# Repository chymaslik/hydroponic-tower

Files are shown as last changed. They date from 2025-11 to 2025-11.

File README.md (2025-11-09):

# Hydroponic Tower Controller

ESPHome custom component for automated hydroponic tower management with pump cycling and lighting control.

## Features

- **Pump Cycle Control**: Automatic ON/OFF cycling with configurable intervals
- **Light Scheduling**: Time-based lighting control with brightness adjustment
- **Web Interface**: Modern, responsive web UI for manual control and monitoring
- **Real-time State**: Live updates of pump and light status
- **REST API**: Full API for integration with Home Assistant or other systems

## Installation

Add this to your ESPHome YAML configuration:

```yaml
external_components:
  - source: github://chymaslik/hydroponic-tower@main
    components: [ hydroponic_controller ]

hydroponic_controller:
  pump_id: water_pump
  light_id: lighting
  time_id: sntp_time
  web_server_id: web_srv
  on_minutes: 5      # Pump ON duration
  off_minutes: 15    # Pump OFF duration
  enabled: false     # Start with schedule disabled
```

## Configuration Variables

- **pump_id** (*Required*, ID): ID of the fan component controlling the pump
- **light_id** (*Required*, ID): ID of the light component
- **time_id** (*Required*, ID): ID of the time component for scheduling
- **web_server_id** (*Required*, ID): ID of the web_server component
- **on_minutes** (*Optional*, int): Pump ON duration in minutes (1-120, default: 5)
- **off_minutes** (*Optional*, int): Pump OFF duration in minutes (1-120, default: 15)
- **enabled** (*Optional*, boolean): Enable pump schedule on startup (default: false)

## Hardware Requirements

- ESP32-C3 (or any ESP32 variant)
- MOSFET modules for pump and lighting control
- Water pump
- LED grow lights
- 12V power supply

## Web Interface

Access the web interface at `http://[device-ip]/` to:
- Manually control pump and lighting
- Configure pump cycle intervals
- Set light schedule (ON/OFF times)
- View real-time events log

## API Endpoints

- `GET /api/state` - Get current state
- `POST /api/pump?on=[0|1]&speed=[0-100]` - Control pump
- `POST /api/pump-cycle?enabled=[0|1]&on=[minutes]&off=[minutes]` - Configure pump schedule
- `POST /api/light?on=[0|1]&brightness=[0-100]` - Control lighting
- `POST /api/light-schedule?enabled=[0|1]&on=[minutes]&off=[minutes]` - Configure light schedule

## Example Configuration

See [hydroponics.yaml](hydroponics.yaml) for a complete working example.

## License

MIT License

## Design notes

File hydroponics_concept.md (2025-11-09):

# Концепция проекта "Умная гидропонная башня"

Этот документ описывает концепцию и компоненты для создания умной гидропонной установки башенного типа на базе 3D-модели "Modular Hydroponic Tower Garden" и микроконтроллера ESP32 с прошивкой ESPHome.

## 1. Концепция системы

Система предназначена для автоматизации ключевых процессов в гидропонной установке: контроль и поддержание уровня питательного раствора, управление освещением и мониторинг ключевых параметров воды (EC и pH).

**Принцип работы:**

- **Контроллер ESP32** является "мозгом" системы. Он собирает данные с сенсоров и управляет исполнительными устройствами.
- **Сенсоры** непрерывно или периодически измеряют параметры окружающей среды и питательного раствора.
- **Исполнительные устройства** (помпа и светодиодная лента) включаются по заданным алгоритмам (например, по расписанию или по показаниям датчиков).
- **Питание** всей системы осуществляется от одного блока питания на 12В, что упрощает конструкцию. Специализированная плата расширения или набор модулей обеспечивает распределение питания на все компоненты.
- **ESPHome** позволяет легко настроить всю логику работы через простой конфигурационный YAML-файл без необходимости глубокого программирования.

### Структурная схема

#### 1. Общая архитектура системы

```mermaid
graph TD;
    subgraph "Питание"
        PSU["Блок питания 12V"];
    end

    subgraph "Управление и Логика"
        CTL["Блок управления<br/>(ESP32 и модули)"];
    end

    subgraph "Исполнительные устройства"
        ACT["Помпа, LED лента"];
    end

    subgraph "Сенсоры и Камера"
        SNS["Все датчики"];
    end

    PSU -->|"12V"| CTL;
    PSU -->|"12V"| ACT;
    CTL -->|"Управляющий сигнал"| ACT;
    SNS -->|"Данные"| CTL;

    style PSU fill:#f9f,stroke:#333,stroke-width:2px;
    style ACT fill:#9cf,stroke:#333,stroke-width:2px;
    style SNS fill:#9cf,stroke:#333,stroke-width:2px;
```

#### 2. Схема подключения сенсоров к ESP32

```mermaid
graph TD;
    ESP32["ESP32 Dev Board"];

    subgraph "Сенсоры и Камера"
        Level["Ультразвуковой датчик уровня<br/>JSN-SR04T"];
        Light["Датчик света<br/>BH1750"];
        AirSensor["Темп. и влажность<br/>BME280"];
        WaterTemp["Температура воды<br/>DS18B20"];
        PH["Датчик pH<br/>DFRobot pH V2"];
        EC["Датчик EC<br/>DFRobot EC V2"];
        WaterFlow["Датчик потока<br/>YF-S201"];
        Camera["ESP32-CAM (Wi-Fi)"];
    end

    Level -- "GPIO23" --> ESP32;
    Light -- "I2C (SDA:21, SCL:22)" --> ESP32;
    AirSensor -- "I2C (SDA:21, SCL:22)" --> ESP32;
    WaterTemp -- "OneWire (GPIO4)" --> ESP32;
    PH -- "ADC (GPIO35)" --> ESP32;
    EC -- "ADC (GPIO34)" --> ESP32;
    WaterFlow -- "GPIO25" --> ESP32;
    Camera -.->|"Wi-Fi/API"| ESP32;
```

## 2. Список компонентов для покупки

Ниже приведен список рекомендованных и совместимых компонентов.

| Компонент | Назначение | Пример / Модель |
| :--- | :--- | :--- |
| **Управление** |
| Микроконтроллер | Мозг системы | ESP32 DEVKIT V1 (или любая плата на ESP-WROOM-32) |
| Плата расширения | Для удобного подключения проводов без пайки | ESP32 Terminal Adapter / Screw Shield |
| **Питание** |
| Блок питания | Питание всей установки | AC/DC 12V, 5A (или больше, в зависимости от длины и мощности ленты) |
| DC-DC Преобразователь | Понижение напряжения с 12В до 5В для ESP32 | DC-DC Step-Down Buck Converter (вход 12V, выход 5V 3A+) |
| **Сенсоры** |
| Ультразвуковой датчик уровня  | Измерение расстояния до воды | Ультразвуковой датчик JSN-SR04T |
| Датчик освещенности | Мониторинг естественного света | GY-30 / BH1750 (I2C интерфейс) |
| Датчик темп. и влажн. воздуха | Контроль микроклимата | BME280 (I2C интерфейс) |
| Датчик температуры воды | Контроль температуры питательного раствора | DS18B20 (в герметичном корпусе) |
| Датчик потока воды | Контроль работы помпы | YF-S201 |
| EC-метр | Измерение электропроводности раствора (концентрация солей) | DFRobot Gravity: Analog EC Sensor/Meter V2 (K=1.0) |
| pH-метр | Измерение кислотности раствора | DFRobot Gravity: Analog pH Sensor/Meter Pro Kit V2 |
| **Исполнительные устройства** |
| Освещение | Круговая фитолампа | Светодиодная лента 12V, фитоспектр. **Длину нужно подбирать под 3D модель!** |
| Драйвер для LED ленты | Управление 12В лентой с помощью ESP32 | MOSFET-модуль (например, IRF520 / AOD4184) |
| Водяная помпа | Подача раствора наверх башни | Погружная помпа DC 12V, производительность ~240-300 л/ч |
| Релейный модуль | Управление 12В помпой с помощью 5В сигнала от ESP32 | 1-канальный релейный модуль 5V |
| **Видеонаблюдение** |
| Камера | Удаленный мониторинг состояния растений | Модуль ESP32-CAM |
| **Прочее** |
| Корпус | Защита электроники от влаги | IP65/IP67 пластиковый корпус |
| Провода | Соединение компонентов | Jumper wires ( Dupont ), провода сечением 0.5мм² |
| Калибровочные растворы | Для точной настройки pH и EC сенсоров | Растворы pH (4.01, 7.00), EC (1413 us/cm, 12.88 ms/cm) |
| Клеммные колодки | Для распределения питания | Винтовые, на 4-8 контактов |

**Примечание по плате расширения:** Вместо поиска одной сложной платы, которая делает все, я рекомендую модульный подход. Установите ESP32 на плату с винтовыми клеммами (Terminal Adapter). Рядом в том же корпусе разместите мощный DC-DC преобразователь 12V->5V и релейный модуль. Это гибкое, надежное и легко обслуживаемое решение.

### 2.1. Распиновка (Pinout)

В таблице ниже приведена рекомендуемая распиновка для всех компонентов, подключаемых к главной плате ESP32.

| Компонент | Тип / Протокол | Пин на ESP32 |
| :--- | :--- | :--- |
| **Сенсоры** |
| Ультразвуковой датчик уровня | Ultrasonic | `Trig: GPIO23`, `Echo: GPIO19` |
| Датчик освещенности (BH1750) | I2C | `SDA: GPIO21`, `SCL: GPIO22` |
| Датчик темп./влажн. (BME280) | I2C | `SDA: GPIO21`, `SCL: GPIO22` |
| Датчик температуры воды (DS18B20) | One-Wire | `GPIO4` |
| Датчик потока воды (YF-S201) | GPIO (Pulse Counter) | `GPIO25` |
| EC-метр (DFRobot) | Analog (ADC) | `GPIO34` |
| pH-метр (DFRobot) | Analog (ADC) | `GPIO35` |
| **Исполнительные устройства** |
| LED лента (через MOSFET) | PWM | `GPIO13` |
| Водяная помпа (через реле) | GPIO (Digital) | `GPIO12` |
| **Камера** |
| ESP32-CAM | Wi-Fi | N/A (отдельное устройство) |

**Что такое АЦП (ADC)?** Это **А**налого-**ц**ифровой **п**реобразователь, встроенный в ESP32. Он нужен для "чтения" показаний с аналоговых датчиков (таких как pH и EC), которые выдают результат в виде изменяющегося напряжения. АЦП преобразует это напряжение в число, понятное микроконтроллеру. Покупать его отдельно не нужно.

### 2.2. Распределение питания

Для такого количества компонентов необходим организованный подход к питанию. Использование клеммных колодок — это лучшее решение, чтобы избежать беспорядка в проводах и обеспечить надежный контакт.

Вся система имеет три основные линии питания: **+12В**, **+5В** и общая **Земля (GND)**. Для правильной работы всех компонентов абсолютно необходимо, чтобы у них была общая "земля" (GND).

- **Линия +12В:** Водяная помпа, Светодиодная лента.
- **Линия +5В:** Плата ESP32, все сенсоры, релейный модуль.
- **Линия GND:** **Все** компоненты системы.

#### Схема организации питания

```mermaid
graph TD;
    subgraph "Источник"
        PSU["Блок питания 12V"];
    end

    subgraph "Преобразователь"
        DCDC["DC-DC 12V -> 5V"];
    end

    subgraph "Распределительные колодки"
        TB12["Клеммная колодка +12V"];
        TB5["Клеммная колодка +5V"];
        TB_GND["<b>Общая клеммная колодка GND</b>"];
    end

    subgraph "Потребители"
        PUMP_LED["Помпа и LED-лента"];
        ESP_SENSORS["ESP32, реле и все сенсоры"];
    end

    %% Connections
    PSU -- "+12V" --> TB12;
    PSU -- "GND" --> TB_GND;

    TB12 -- "+12V" --> DCDC;
    TB_GND -- "GND" --> DCDC;

    DCDC -- "+5V" --> TB5;

    TB12 -- "+12V" --> PUMP_LED;
    TB_GND -- "GND" --> PUMP_LED;

    TB5 -- "+5V" --> ESP_SENSORS;
    TB_GND -- "GND" --> ESP_SENSORS;

    style TB_GND fill:#ccc,stroke:#333,stroke-width:2px;
```

## 3. Программное обеспечение: ESPHome

ESPHome позволяет описать всю логику работы устройства в одном файле. Вся конфигурация для основного контроллера вынесена в файл `

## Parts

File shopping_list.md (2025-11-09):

# Список покупок для проекта "Умная гидропоника"

Ниже приведен список компонентов с поисковыми ссылками для сайта AliExpress.

| Компонент | Пример / Модель | Ссылка для поиска на AliExpress |
| :--- | :--- | :--- |
| **Управление** |
| Микроконтроллер | ESP32 DEVKIT V1 | [Найти](https://www.aliexpress.com/wholesale?SearchText=ESP32+DEVKIT+V1) |
| Плата расширения | ESP32 Terminal Adapter | [Найти](https://www.aliexpress.com/wholesale?SearchText=ESP32+Terminal+Adapter) |
| **Питание** |
| Блок питания | AC/DC 12V 5A | [Найти](https://www.aliexpress.com/wholesale?SearchText=power+supply+12v+5a) |
| DC-DC Преобразователь | DC-DC Step-Down LM2596S | [Найти](https://www.aliexpress.com/wholesale?SearchText=DC-DC+Step+Down+LM2596S) |
| **Сенсоры** |
| Датчик уровня воды | Ультразвуковой датчик JSN-SR04T | [Найти](https://www.aliexpress.com/wholesale?SearchText=JSN-SR04T) |
| Датчик освещенности | BH1750 | [Найти](https://www.aliexpress.com/wholesale?SearchText=BH1750+module) |
| Датчик темп./влажн. | BME280 | [Найти](https://www.aliexpress.com/wholesale?SearchText=BME280+module) |
| Датчик темп. воды | DS18B20 (водонепроницаемый) | [Найти](https://www.aliexpress.com/wholesale?SearchText=DS18B20+waterproof) |
| Датчик потока воды | YF-S201 | [Найти](https://www.aliexpress.com/wholesale?SearchText=YF-S201+water+flow) |
| EC-метр | TDS / EC Sensor Module | [Найти](https://www.aliexpress.com/wholesale?SearchText=TDS+EC+sensor+module) |
| pH-метр | pH Sensor Module (0-14 pH) | [Найти](https://www.aliexpress.com/wholesale?SearchText=pH+sensor+module+0-14) |
| **Исполнительные устройства** |
| Освещение | 12V Phyto LED Strip | [Найти](https://www.aliexpress.com/wholesale?SearchText=12v+phyto+led+strip+full+spectrum) |
| Драйвер для LED | IRF520 MOSFET Module | [Найти](https://www.aliexpress.com/wholesale?SearchText=IRF520+MOSFET+module) |
| Водяная помпа | Погружная помпа 12V 240L/h | [Найти](https://www.aliexpress.com/wholesale?SearchText=mini+submersible+pump+12v+240L) |
| Релейный модуль | 1-канальное реле 5V | [Найти](https://www.aliexpress.com/wholesale?SearchText=1+channel+relay+module+5v) |
| **Видеонаблюдение** |
| Камера | ESP32-CAM | [Найти](https://www.aliexpress.com/wholesale?SearchText=ESP32-CAM+MB) |
| **Прочее** |
| Провода | Dupont Jumper Wires | [Найти](https://www.aliexpress.com/wholesale?SearchText=dupont+jumper+wires) |
| Калибровочные растворы | pH & EC Calibration Solution | [Найти](https://www.aliexpress.com/wholesale?SearchText=ph+ec+calibration+solution) |
| Клеммные колодки | Screw Terminal Block | [Найти](https://www.aliexpress.com/wholesale?SearchText=screw+terminal+block) |

**Совет:** При покупке pH и EC сенсоров обратите внимание на комплектацию. Часто калибровочные растворы (в виде порошков) уже идут в комплекте с ними. Также, при покупке ESP32-CAM, выбирайте версию с программатором (MB), это сильно упростит первую прошивку.

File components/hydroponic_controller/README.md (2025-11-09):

# Hydroponic Controller Component

ESPHome custom component for hydroponic systems automation.

## Files

- `__init__.py` - Component configuration and setup
- `hydroponic_controller.h` - Main controller implementation with web interface

## Usage

See main [README.md](../../README.md) for installation and configuration instructions.

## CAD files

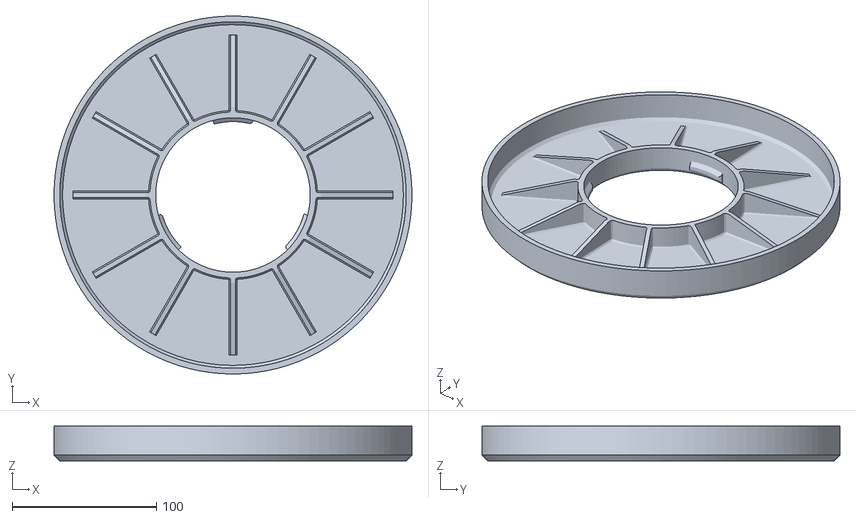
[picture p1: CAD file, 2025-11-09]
3d parts/ikea_muskot_pot_7_12_adapter_id240mm_full.stl
248.0 x 248.0 x 24.0

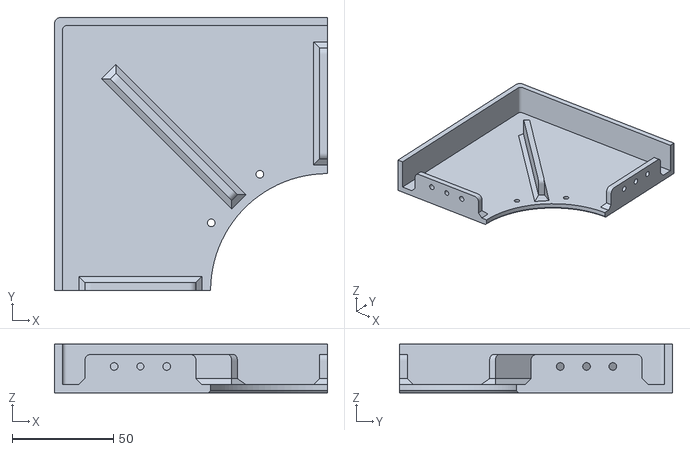
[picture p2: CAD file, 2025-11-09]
3d parts/lid v1.stl
135.0 x 135.0 x 24.0

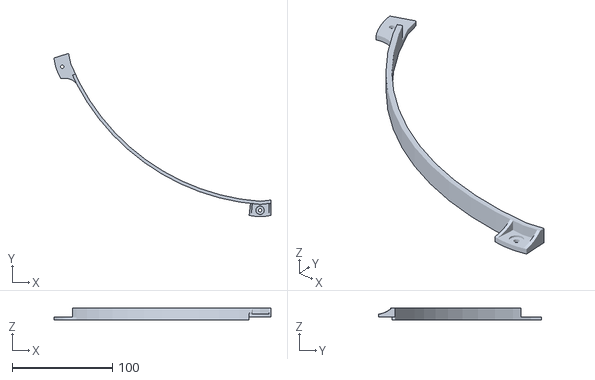
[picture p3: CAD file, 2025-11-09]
3d parts/rings_large_v42.stl
216.4 x 162.7 x 12.0

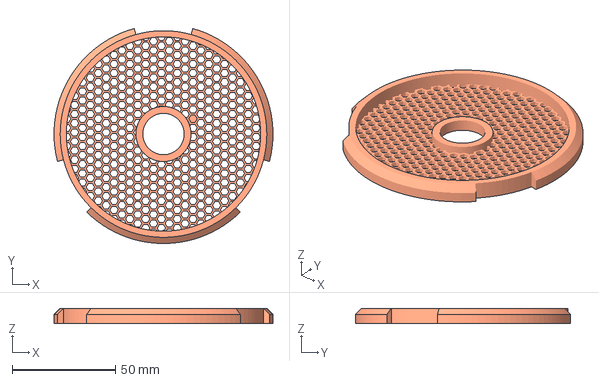
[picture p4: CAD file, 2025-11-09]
3d parts/filtration_mesh_remix.3mf
106.0 x 104.0 x 7.50 mm

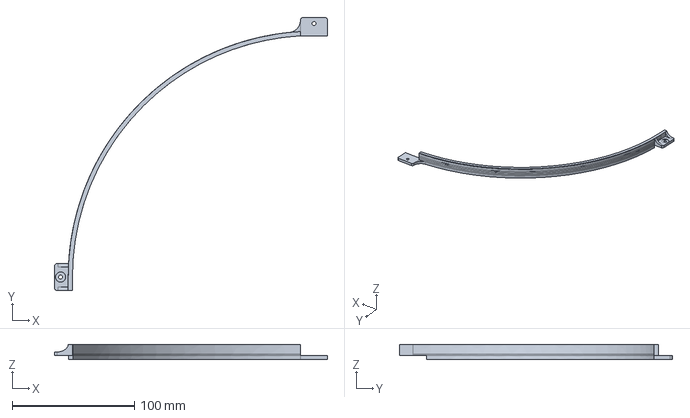
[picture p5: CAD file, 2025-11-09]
3d parts/ring_piece_for_4_way_cup.stp
223.2 x 223.2 x 12.0 mm

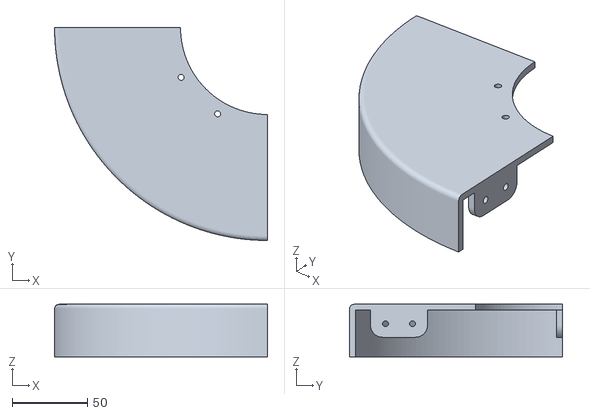
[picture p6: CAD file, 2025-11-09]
3d parts/Soporte_Basic.stl
142.0 x 142.0 x 35.0

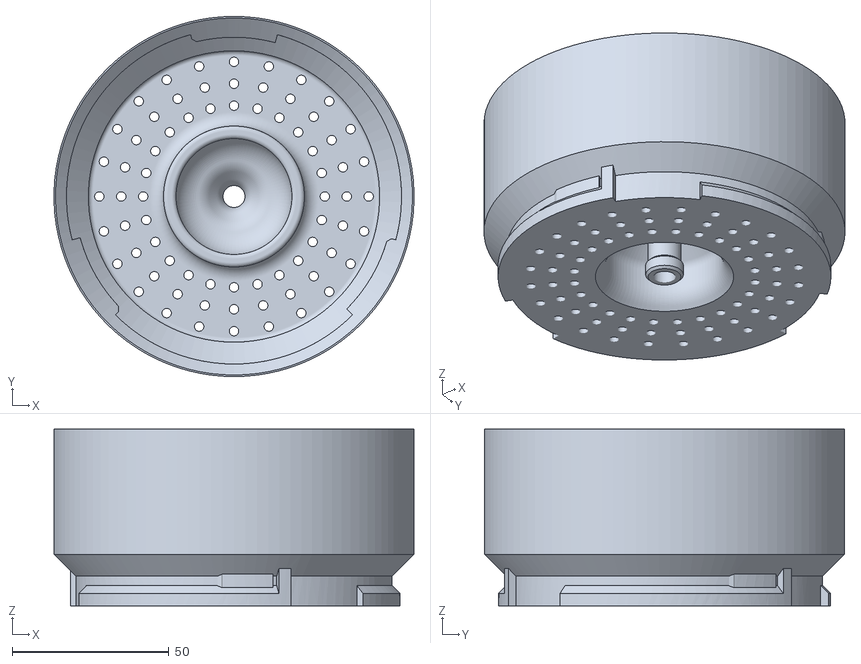
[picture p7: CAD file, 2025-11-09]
3d parts/dispenser_module_internal.stl
114.9 x 115.0 x 56.5

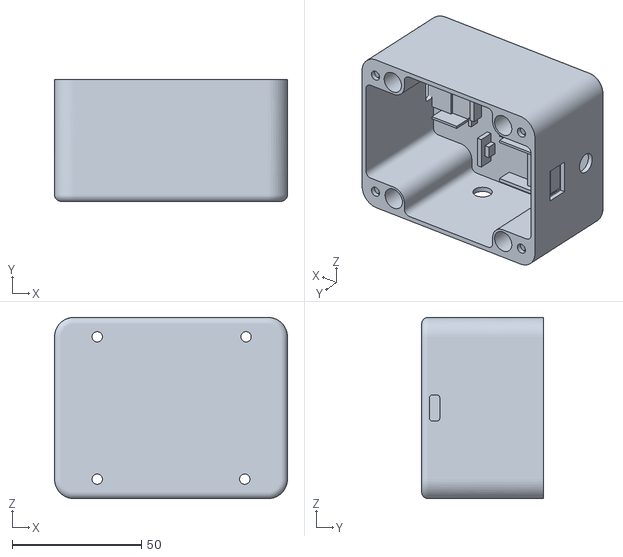
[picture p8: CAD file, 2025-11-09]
3d parts/electronic-box.stl
90.0 x 47.0 x 70.0

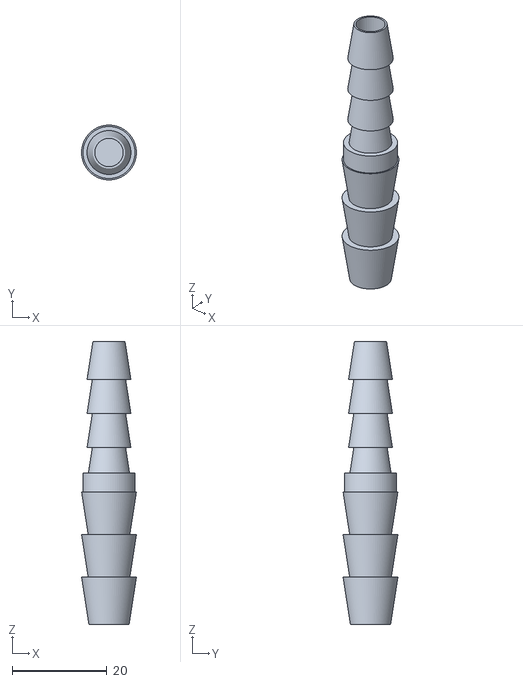
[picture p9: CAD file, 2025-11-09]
3d parts/10mmTo8mmHoseBarbAdapter.stl
11.6 x 11.6 x 59.8

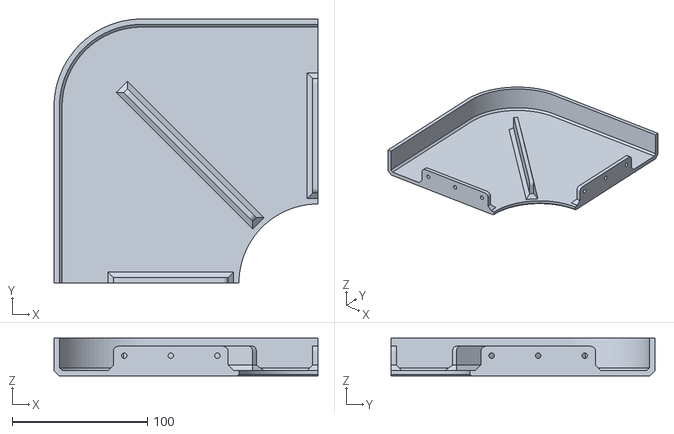
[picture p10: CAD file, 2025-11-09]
3d parts/oestlig_plant_pot_14_12x14_12_adapter.stl
195.5 x 195.5 x 28.0

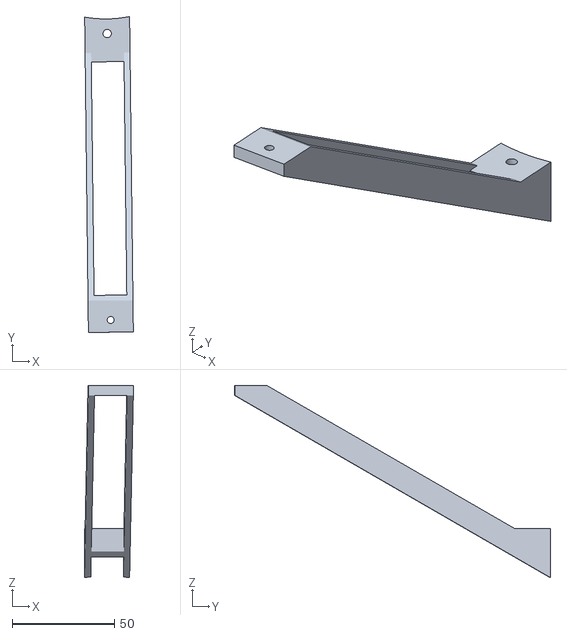
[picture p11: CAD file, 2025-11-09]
3d parts/arm_v2.stl
23.8 x 154.6 x 94.0

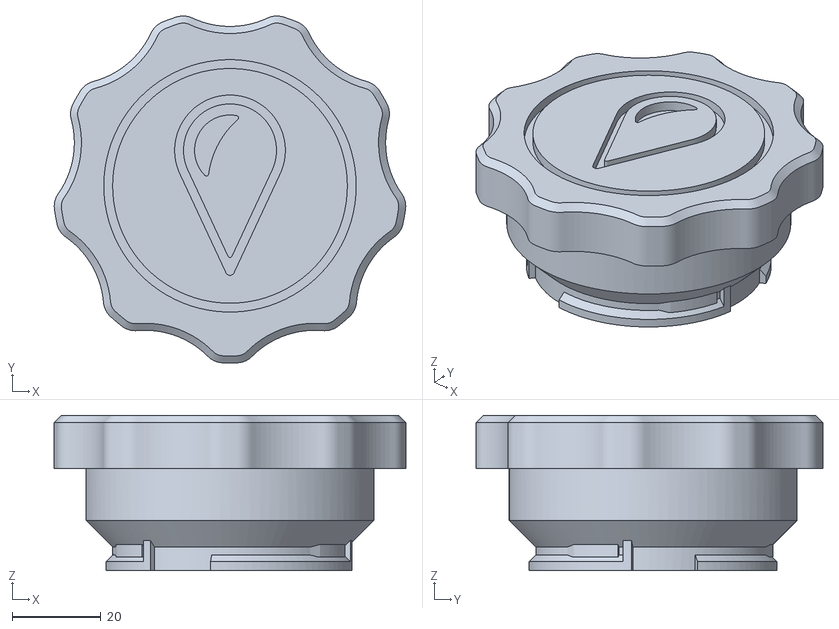
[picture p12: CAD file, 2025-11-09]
3d parts/filling_cap.stl
79.4 x 78.4 x 35.0

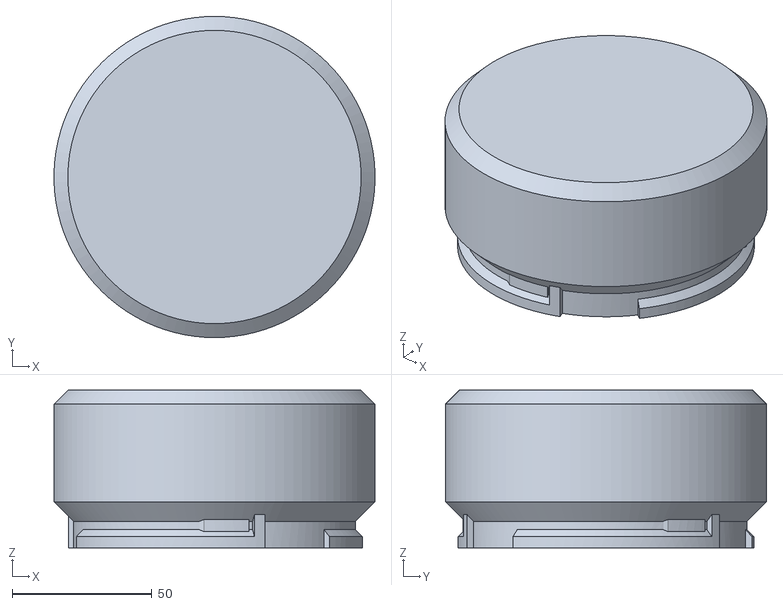
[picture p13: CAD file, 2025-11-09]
3d parts/lid_without_holes.stl
114.9 x 115.0 x 56.5

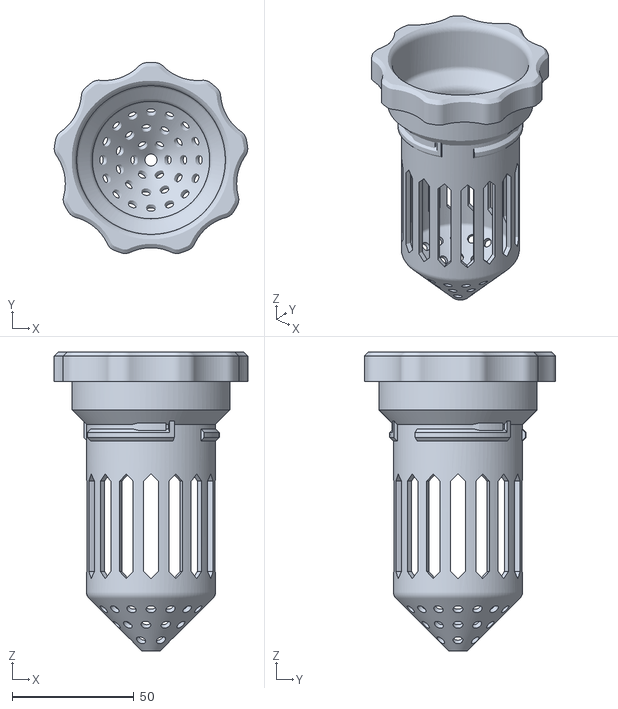
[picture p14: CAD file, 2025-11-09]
3d parts/standard_pot.stl
79.4 x 78.4 x 122.6

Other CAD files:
3d parts/3-way_planting_module_hollow.stl
3d parts/waterpump_hose_adapter.stl
3d parts/electronic-box-top.stl
3d parts/Base.stl
3d parts/1-way_planting_module_hollow_without_m3.stl
3d parts/4-way_planting_module_hollow.stl
3d parts/pump_holder.stl
3d parts/washer.stl

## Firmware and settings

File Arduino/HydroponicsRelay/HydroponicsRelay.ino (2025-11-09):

// Подключение Wi‑Fi и Web‑сервер
#include <WiFi.h>
#include <WebServer.h>
#include <time.h>
#include <sys/time.h>
#include <Preferences.h>

// Конфигурация пинов реле:
// IN1 -> GPIO41 (Lighting), IN2 -> GPIO42 (Pump)
const int relayLightingPin = 41;  // Канал 1 — освещение (IN1)
const int relayPumpPin     = 42;  // Канал 2 — помпа (IN2)

// Логика срабатывания реле: true для HIGH‑level (RY‑VCC↔VCC), false для LOW‑level (VOC↔GND)
const bool relayActiveHigh = false;  // инвертировано

// Скорость Serial для управления из монитора порта
const unsigned long serialBaudRate = 115200;

// Настройки Wi‑Fi (замените на свои)
const char* WIFI_SSID     = "Smart Home";
const char* WIFI_PASSWORD = "qazwsxedc";

// NTP/время
bool   ntpEnabled   = true;
long   gmtOffsetSec = 0;           // смещение от UTC в секундах
const char* NTP1 = "pool.ntp.org";
const char* NTP2 = "time.nist.gov";
unsigned long lastTimeSyncCheckMs = 0;

// NVS
Preferences prefs;

// HTTP сервер
WebServer server(80);
// Кольцевой буфер для последних N событий
struct Event { unsigned long ts; String msg; };
const size_t MAX_EVENTS = 50;
Event events[MAX_EVENTS];
size_t eventsHead = 0, eventsCount = 0;

// Параметры: помпа — циклический скедулер (в минутах)
struct CycleCfg { bool enabled; uint16_t onMin; uint16_t offMin; unsigned long lastTickMs; bool currentlyOn; };
CycleCfg schedPump { false, 1, 14, 0, false };

// Параметры: свет — расписание по времени суток (минуты с начала дня)
struct ClockCfg { bool enabled; uint16_t onMins; uint16_t offMins; bool lastAppliedOn; };
ClockCfg lightClock { false, 6*60, 22*60, false };

void saveConfig() {
  if (!prefs.begin("hydro", false)) return;
  prefs.putBool ("ntp", ntpEnabled);
  prefs.putLong ("tz",  gmtOffsetSec);
  prefs.putBool ("p_en", schedPump.enabled);
  prefs.putUShort("p_on", schedPump.onMin);
  prefs.putUShort("p_off",schedPump.offMin);
  prefs.putBool ("l_en", lightClock.enabled);
  prefs.putUShort("l_on", lightClock.onMins);
  prefs.putUShort("l_off",lightClock.offMins);
  prefs.end();
}

void loadConfig() {
  if (!prefs.begin("hydro", true)) return;
  ntpEnabled          = prefs.getBool ("ntp", ntpEnabled);
  gmtOffsetSec        = prefs.getLong ("tz",  gmtOffsetSec);
  schedPump.enabled   = prefs.getBool ("p_en", schedPump.enabled);
  schedPump.onMin     = prefs.getUShort("p_on", schedPump.onMin);
  schedPump.offMin    = prefs.getUShort("p_off",schedPump.offMin);
  lightClock.enabled  = prefs.getBool ("l_en", lightClock.enabled);
  lightClock.onMins   = prefs.getUShort("l_on", lightClock.onMins);
  lightClock.offMins  = prefs.getUShort("l_off", lightClock.offMins);
  prefs.end();
}

void pushEvent(const String &m) {
  events[eventsHead] = { millis(), m };
  eventsHead = (eventsHead + 1) % MAX_EVENTS;
  if (eventsCount < MAX_EVENTS) eventsCount++;
}

void setRelayState(int pinNumber, bool shouldTurnOn) {
  const int activeState   = relayActiveHigh ? HIGH : LOW;
  const int inactiveState = relayActiveHigh ? LOW  : HIGH;
  digitalWrite(pinNumber, shouldTurnOn ? activeState : inactiveState);
  String name = (pinNumber == relayLightingPin) ? F("Lighting") : F("Water pump");
  pushEvent(name + (shouldTurnOn ? F(" -> ON") : F(" -> OFF")));
}

void applyPumpCycle(CycleCfg &cfg, int pin) {
  if (!cfg.enabled) return;
  unsigned long now = millis();
  if (cfg.lastTickMs == 0) cfg.lastTickMs = now;
  unsigned long periodMs = (unsigned long)(cfg.currentlyOn ? cfg.onMin : cfg.offMin) * 60UL * 1000UL;
  if (periodMs == 0) return;
  if (now - cfg.lastTickMs >= periodMs) {
    cfg.currentlyOn = !cfg.currentlyOn;
    cfg.lastTickMs = now;
    setRelayState(pin, cfg.currentlyOn);
  }
}

// Вспомогательные функции для времени
bool getLocalTM(struct tm &out) {
  time_t now; time(&now);
  if (now < 100000) return false; // время не синхронизировано
  struct tm *lt = localtime(&now);
  if (!lt) return false;
  out = *lt; return true;
}

uint16_t hhmmToMins(const String &s) {
  int p = s.indexOf(':');
  if (p <= 0) return 0;
  int hh = s.substring(0,p).toInt();
  int mm = s.substring(p+1).toInt();
  if (hh < 0) hh=0; if (hh>23) hh=23; if (mm<0) mm=0; if (mm>59) mm=59;
  return (uint16_t)(hh*60+mm);
}

String minsToHHMM(uint16_t m) {
  uint16_t hh = (m/60)%24; uint16_t mm = m%60;
  char buf[6]; snprintf(buf,sizeof(buf), "%02u:%02u", (unsigned)hh,(unsigned)mm);
  return String(buf);
}

void applyLightByClock() {
  if (!lightClock.enabled) return;
  struct tm lt; if (!getLocalTM(lt)) return;
  uint16_t nowM = (uint16_t)(lt.tm_hour*60 + lt.tm_min);
  bool shouldOn;
  if (lightClock.onMins == lightClock.offMins) {
    shouldOn = false;
  } else if (lightClock.onMins < lightClock.offMins) {
    shouldOn = (nowM >= lightClock.onMins && nowM < lightClock.offMins);
  } else {
    // период через полночь
    shouldOn = (nowM >= lightClock.onMins || nowM < lightClock.offMins);
  }
  if (shouldOn != lightClock.lastAppliedOn) {
    lightClock.lastAppliedOn = shouldOn;
    setRelayState(relayLightingPin, shouldOn);
  }
}

void ensureTimeSync() {
  if (!ntpEnabled) return;
  if (WiFi.status() != WL_CONNECTED) return;
  unsigned long now = millis();
  if (lastTimeSyncCheckMs!=0 && now - lastTimeSyncCheckMs < 60000UL) return;
  lastTimeSyncCheckMs = now;
  static bool configured = false;
  if (!configured) {
    configTime(gmtOffsetSec, 0, NTP1, NTP2);
    configured = true;
  }
}

void printStatus() {
  int lightLevel = digitalRead(relayLightingPin);
  int pumpLevel  = digitalRead(relayPumpPin);
  const int activeState   = relayActiveHigh ? HIGH : LOW;
  Serial.println();
  Serial.println(F("== Relay status =="));
  Serial.print(F("Lighting: ")); Serial.println(lightLevel == activeState ? F("ON") : F("OFF"));
  Serial.print(F("Pump    : ")); Serial.println(pumpLevel  == activeState ? F("ON") : F("OFF"));
  Serial.println();
}

String jsonStatus() {
  const int activeState = relayActiveHigh ? HIGH : LOW;
  bool lightOn = (digitalRead(relayLightingPin) == activeState);
  bool pumpOn  = (digitalRead(relayPumpPin)     == activeState);
  struct tm lt; bool tv = getLocalTM(lt);
  char tbuf[20]=""; if (tv) snprintf(tbuf,sizeof(tbuf), "%04d-%02d-%02d %02d:%02d:%02d",
    lt.tm_year+1900, lt.tm_mon+1, lt.tm_mday, lt.tm_hour, lt.tm_min, lt.tm_sec);
  String json = "{";
  json += "\"lighting\":"; json += lightOn?"true":"false";
  json += ",\"pump\":";     json += pumpOn?"true":"false";
  json += ",\"time\":\"";   json += String(tbuf); json += "\"";
  json += ",\"ntp\":";      json += ntpEnabled?"true":"false";
  json += ",\"tz\":";       json += gmtOffsetSec;
  json += ",\"sched\":{\"lightClock\":{\"en\":"; json += lightClock.enabled?"true":"false";
  json += ",\"on\":\""; json += minsToHHMM(lightClock.onMins); json += "\"";
  json += ",\"off\":\""; json += minsToHHMM(lightClock.offMins); json += "\"";
  json += "},\"pump\":{\"en\":"; json += schedPump.enabled?"true":"false"; json += ",\"on\":"; json += schedPump.onMin; json += ",\"off\":"; json += schedPump.offMin; json += "}}}";
  return json;
}

void handleStatus() {
  server.sendHeader("Cache-Control", "no-cache, no-store, must-revalidate");
  server.sendHeader("Pragma", "no-cache");
  server.sendHeader("Expires", "0");
  server.send(200, "application/json", jsonStatus());
}

void handleRelayApi() {
  // /api/relay?ch=1&on=1
  if (!server.hasArg("ch") || !server.hasArg("on")) {
    server.send(400, "application/json", "{\"error\":\"params ch,on required\"}");
    return;
  }
  int ch = server.arg("ch").toInt();
  bool on = (server.arg("on") == "1" || server.arg("on") == "true");
  if (ch == 1)      { setRelayState(relayLightingPin, on); lightClock.lastAppliedOn = on; }
  else if (ch == 2) { setRelayState(relayPumpPin, on);     schedPump.currentlyOn  = on; schedPump.lastTickMs  = millis(); }
  else { server.send(400, "application/json", "{\"error\":\"ch must be 1 or 2\"}"); return; }
  server.sendHeader("Cache-Control", "no-cache, no-store, must-revalidate");
  server.sendHeader("Pragma", "no-cache");
  server.sendHeader("Expires", "0");
  server.send(200, "application/json", jsonStatus());
}

void handleEvents() {
  String json = "[";
  for (size_t i = 0; i < eventsCount; i++) {
    size_t idx = (eventsHead + MAX_EVENTS - eventsCount + i) % MAX_EVENTS;
    if (i) json += ',';
    json += '{';
    json += "\"ts\":"; json += events[idx].ts; json += ',';
    json += "\"msg\":\""; json += events[idx].msg; json += "\"";
    json += '}';
  }
  json += "]";
  server.sendHeader("Cache-Control", "no-cache, no-store, must-revalidate");
  server.sendHeader("Pragma", "no-cache");
  server.sendHeader("Expires", "0");
  server.send(200, "application/json", json);
}

void handleSchedulePump() {
  // /api/schedule_pump?en=1&on=1&off=14  (минуты)
  if (server.hasArg("en"))  schedPump.enabled = (server.arg("en")=="1" || server.arg("en")=="true");
  if (server.hasArg("on"))  schedPump.onMin   = (uint16_t) server.arg("on").toInt();
  if (server.hasArg("off")) schedPump.offMin  = (uint16_t) server.arg("off").toInt();
  schedPump.lastTickMs = millis();
  saveConfig();
  server.sendHeader("Cache-Control", "no-cache, no-store, must-revalidate");
  server.sendHeader("Pragma", "no-cache");
  server.sendHeader("Expires", "0");
  server.send(200, "application/json", jsonStatus());
}

void handleScheduleLight() {
  // /api/schedule_light?en=1&on=HH:MM&off=HH:MM
  if (server.hasArg("en"))  lightClock.enabled = (server.arg("en")=="1" || server.arg("en")=="true");
  if (server.hasArg("on"))  lightClock.onMins  = hhmmToMins(server.arg("on"));
  if (server.hasArg("off")) lightClock.offMins = hhmmToMins(server.arg("off"));
  saveConfig();
  server.sendHeader("Cache-Control", "no-cache, no-store, must-revalidate");
  server.sendHeader("Pragma", "no-cache");
  server.sendHeader("Expires", "0");
  server.send(200, "application/json", jsonStatus());
}

void handleTimeConfig() {
  // /api/time?ntp=1&tz=10800   |  /api/time?epoch=...
  if (server.hasArg("ntp")) ntpEnabled = (server.arg("ntp")=="1" || server.arg("ntp")=="true");
  if (server.hasArg("tz"))  gmtOffsetSec = server.arg("tz").toInt();
  if (server.hasArg("epoch")) {
    time_t e = (time_t) server.arg("epoch").toInt();
    struct timeval tv{ .tv_sec = e, .tv_usec = 0 }; settimeofday(&tv, nullptr);
  }
  if (ntpEnabled && WiFi.status()==WL_CONNECTED) { configTime(gmtOffsetSec, 0, NTP1, NTP2); }
  saveConfig();
  server.sendHeader("Cache-Control", "no-cache, no-store, must-revalidate");
  server.sendHeader("Pragma", "no-cache");
  server.sendHeader("Expires", "0");
  server.send(200, "application/json", jsonStatus());
}

const char INDEX_HTML[] PROGMEM = R"HTML(
<!doctype html><html><head><meta charset="utf-8"><meta name="viewport" content="width=device-width,initial-scale=1">
<title>Hydroponic Tower</title>
<style>
  :root{--bg:#121212;--fg:#e6e6e6;--muted:#9aa0a6;--card:#1e1e1e;--acc:#4dd0e1;--on:#00e676;--off:#ff5252}
  body{margin:0;background:var(--bg);color:var(--fg);font:16px/1.4 system-ui,Segoe UI,Roboto,Ubuntu}
  .wrap{max-width:980px;margin:24px auto;padding:0 16px}
  h1{font-size:28px;margin:10px 0 18px}
  table{width:100%;border-collapse:collapse;background:var(--card);border-radius:10px;overflow:hidden}
  th,td{padding:12px 14px;border-bottom:1px solid #2a2a2a}
  th{color:var(--muted);text-align:left;font-weight:600}
  .row:last-child td{border-bottom:none}
  .actions{white-space:nowrap}
  .grid{display:grid;grid-template-columns:1fr;gap:16px;margin-top:18px}
  .card{background:var(--card);padding:12px 14px;border-radius:10px}
  .log{max-height:240px;overflow:auto;font-family:ui-monospace,Consolas,monospace;font-size:13px}
  .muted{color:var(--muted)}
  .sw{position:relative;display:inline-block;width:54px;height:28px;vertical-align:middle;margin-left:10px}
  .sw input{display:none}
  .slider{position:absolute;inset:0;background:#3a3a3a;border-radius:28px;transition:.18s}
  .slider:before{content:"";position:absolute;left:3px;top:3px;width:22px;height:22px;background:#fff;border-radius:50%;transition:.18s}
  input:checked+.slider{background:var(--on)}
  input:checked+.slider:before{transform:translateX(26px)}
  input[type=number],input[type=time]{width:110px;padding:6px 8px;border-radius:6px;border:1px solid #2a2a2a;background:#252525;color:var(--fg);} 
  label.small{font-size:12px;color:var(--muted);margin-right:8px}
  @media(max-width:720px){.grid{grid-template-columns:1fr}}
</style></head>
<body><div class="wrap">
  <h1>Hydroponic Tower</h1>
  <table>
    <tr><th style="width:40%">Name</th><th>State / Schedule</th></tr>
    <tr class="row"><td>Lighting</td>
      <td class="actions">
        <label class="sw"><input id="tL" type="checkbox"><span class="slider"></span></label>
        <label class="small">Enable</label><input id="enLC" type="checkbox">
        <label class="small">ON</label><input id="onLC" type="time" value="06:00">
        <label class="small">OFF</label><input id="offLC" type="time" value="22:00">
      </td></tr>
    <tr class="row"><td>Water pump</td>
      <td class="actions">
        <label class="sw"><input id="tP" type="checkbox"><span class="slider"></span></label>
        <label class="small">Enable</label><input id="enP" type="checkbox">
        <label class="small">ON (min)</label><input id="onP" type="number" min="0" value="1">
        <label class="small">OFF (min)</label><input id="offP" type="number" min="0" value="14">
      </td></tr>
  </table>
  <div class="grid">
    <div class="card">
      <div class="muted">Time</div>
      <div id="timeBox" class="muted">--</div>
    </div>
    <div class="card">
      <div class="muted">Events</div>
      <pre id="ev" class="log"></pre>
    </div>
  </div>
  <p class="muted" style="margin-top:14px">API: <a href="/api/status">/api/status</a>, <a href="/api/events">/api/events</a>, <code>/api/relay?ch=1&on=1</code>, <code>/api/schedule_pump?en=1&on=1&off=14</code>, <code>/api/schedule_light?en=1&on=06:00&off=22:00</code>, <code>/api/time?ntp=1&tz=10800</code>, <code>/api/time?epoch=...</code></p>
</div>
<script src="/app.js"></script>
</body></html>
)HTML";

void handleIndex() { server.send_P(200, "text/html", INDEX_HTML); }

void setupWebServer() {
  server.on("/", HTTP_GET, handleIndex);
  server.on("/api/status", HTTP_GET, handleStatus);
  server.on("/api/relay", HTTP_GET, handleRelayApi);
  server.on("/api/events", HTTP_GET, handleEvents);
  server.on("/api/schedule_pump", HTTP_GET, handleSchedulePump);
  server.on("/api/schedule_light", HTTP_GET, handleScheduleLight);
  server.on("/api/time", HTTP_GET, handleTimeConfig);
  // JS
  server.on("/app.js", HTTP_GET, [](){
    static const char APP_JS[] PROGMEM = R"JS(
const tL=document.getElementById('tL');
const tP=document.getElementById('tP');
const enP=document.getElementById('enP');
const onP=document.getElementById('onP');
const offP=document.getElementById('offP');
const enLC=document.getElementById('enLC');
const onLC=document.getElementById('onLC');
const offLC=document.getElementById('offLC');
const ev=document.getElementById('ev');
const timeBox=document.getElementById('timeBox');

// поля, которые нельзя перетирать во время ввода
const editing=new Set();
['enP','onP','offP','enLC','onLC','offLC'].forEach(id=>{
  const el=document.getElementById(id);
  el.addEventListener('focus',()=>editing.add(id));
  el.addEventListener('blur',()=>{ editing.delete(id); load(); });
});

async function api(url){ await fetch(url,{cache:'no-store'}); }
async function apiSet(ch,on){ await api(`/api/relay?ch=${ch}&on=${on?1:0}&t=${Date.now()}`); }
async function apiSchedPump(){ await api(`/api/schedule_pump?en=${enP.checked?1:0}&on=${onP.value}&off=${offP.value}&t=${Date.now()}`); }
async function apiSchedLight(){ await api(`/api/schedule_light?en=${enLC.checked?1:0}&on=${onLC.value}&off=${offLC.value}&t=${Date.now()}`); }
async function apiTimeTZEpoch(tzSec,epoch){ await api(`/api/time?tz=${tzSec}&epoch=${epoch}&t=${Date.now()}`); }

let didAutoSync=false;
async function autoSync(){
  if(didAutoSync) return; didAutoSync=true;
  const tzSec = -new Date().getTimezoneOffset()*60; // сек. восточнее UTC
  const epoch = Math.floor(Date.now()/1000);
  await apiTimeTZEpoch(tzSec,epoch);
}

async function load(){
  const r=await fetch(`/api/status?t=${Date.now()}`,{cache:'no-store'}); const j=await r.json();
  // тумблеры
  tL.checked=!!j.lighting; tP.checked=!!j.pump;
  // помпа — только если поле не редактируется
  if(!editing.has('enP'))   enP.checked=!!j.sched.pump.en;
  if(!editing.has('onP'))   onP.value=j.sched.pump.on;
  if(!editing.has('offP'))  offP.value=j.sched.pump.off;
  // свет по часам
  if(!editing.has('enLC'))  enLC.checked=!!j.sched.lightClock.en;
  if(!editing.has('onLC'))  onLC.value=j.sched.lightClock.on;
  if(!editing.has('offLC')) offLC.value=j.sched.lightClock.off;
  // время
  timeBox.textContent=j.time||'--';
  // события
  const e=await fetch(`/api/events?t=${Date.now()}`,{cache:'no-store'}); const ej=await e.json();
  ev.textContent=ej.map(x=>`${(x.ts/1000).toFixed(1)}  ${x.msg}`).reverse().join('\n');
}

tL.addEventListener('change',()=>apiSet(1,tL.checked));
tP.addEventListener('change',()=>apiSet(2,tP.checked));
enP.addEventListener('change',apiSchedPump);
onP.addEventListener('change',apiSchedPump);
offP.addEventListener('change',apiSchedPump);

enLC.addEventListener('change',apiSchedLight);
onLC.addEventListener('change',apiSchedLight);
offLC.addEventListener('change',apiSchedLight);

setInterval(load,1500);
autoSync().then(load);
)JS";
    server.sendHeader("Cache-Control","no-cache, no-store, must-revalidate");
    server.sendHeader("Pragma","no-cache");
    server.sendHeader("Expires","0");
    server.send_P(200, "application/javascript", APP_JS);
  });
  server.begin();
}

void connectWiFi() {
  WiFi.mode(WIFI_STA);
  WiFi.begin(WIFI_SSID, WIFI_PASSWORD);
  unsigned long start = millis();
  while (WiFi.status() != WL_CONNECTED && millis() - start < 20000) { delay(250); Serial.print('.'); }
  Serial.println();
  if (WiFi.status() == WL_CONNECTED) {
    Serial.print(F("WiFi connected, IP: ")); Serial.println(WiFi.localIP());
  } else {
    Serial.println(F("WiFi not connected (timeout)"));
  }
}

String readLineFromSerial() {
  static String buffer; while (Serial.available() > 0) { char c = (char)Serial.read(); if (c=='\n'||c=='\r'){ if(buffer.length()>0){ String line=buffer; buffer=""; return line; } } else { buffer+=c; } } return String(); }

void handleCommand(const String &raw) {
  String cmd = raw; cmd.trim(); cmd.toLowerCase();
  if (cmd == "help" || cmd == "h") {
    Serial.println(F("Commands:"));
    Serial.println(F("  light on/off | l on/off"));
    Serial.println(F("  pump on/off  | p on/off"));
    Serial.println(F("  schedule_pump en=1 on=1 off=14"));
    Serial.println(F("  schedule_light en=1 on=HH:MM off=HH:MM"));
    Serial.println(F("  time ntp=1 tz=10800 | time epoch=..."));
    Serial.println(F("  status"));
    return;
  }
  if (cmd == "status") { printStatus(); return; }
}

void setup() {
  Serial.begin(serialBaudRate); delay(200);
  loadConfig();
  pinMode(relayLightingPin, OUTPUT); pinMode(relayPumpPin, OUTPUT);
  setRelayState(relayLightingPin, false); setRelayState(relayPumpPin, false);
  Serial.println(F("Hydroponics Relay Controller (ESP32-S3)"));
  connectWiFi(); ensureTimeSync();
  server.stop(); setupWebServer();
}

void loop() {
  ensureTimeSync();
  applyLightByClock();
  applyPumpCycle(schedPump,  relayPumpPin);
  server.handleClient();
}

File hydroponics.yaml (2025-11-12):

# ===========================================
# ESP32-C3 SuperMini - Hydroponic Tower
# ===========================================

substitutions:
  build_number: "2024.11.12.002"

esphome:
  name: hydroponic-tower
  friendly_name: Hydroponic Tower
  comment: Build ${build_number}

esp32:
  board: esp32-c3-devkitm-1
  framework:
    type: arduino

logger:
  level: DEBUG
  logs:
    hydroponic_controller: DEBUG

wifi:
  ssid: !secret wifi_ssid
  password: !secret wifi_password
  
  ap:
    ssid: "Hydroponics"
    password: "12345678"

web_server:
  id: web_srv
  port: 80
  version: 2

api:
  encryption:
    key: !secret api_key
  reboot_timeout: 0s  # Отключить автоматическую перезагрузку при потере API

ota:
  - platform: esphome
    password: !secret ota_password
  - platform: web_server  # OTA через веб интерфейс

# Синхронизация времени
time:
  - platform: sntp
    id: sntp_time
    timezone: Europe/Kiev
    servers:
      - 0.pool.ntp.org
      - 1.pool.ntp.org

# PWM выходы для MOSFET модулей
output:
  - platform: ledc
    pin: GPIO5
    id: pwm_lighting
    frequency: 1000Hz
    
  - platform: ledc
    pin: GPIO4
    id: pwm_pump
    frequency: 1000Hz

# Управление освещением (вкл/выкл + яркость)
light:
  - platform: monochromatic
    name: "Lighting"
    id: lighting
    output: pwm_lighting
    restore_mode: ALWAYS_OFF
    default_transition_length: 0s

# Управление помпой (вкл/выкл + мощность)
fan:
  - platform: speed
    name: "Water Pump"
    id: water_pump
    output: pwm_pump
    restore_mode: ALWAYS_OFF
    speed_count: 100

# Restart switch
switch:
  - platform: restart
    name: "Restart"

# Мониторинг производительности
debug:
  update_interval: 5s

sensor:
  # WiFi сигнал
  - platform: wifi_signal
    name: "WiFi Signal"
    update_interval: 60s
    
  # Время работы
  - platform: uptime
    name: "Uptime"
    update_interval: 60s
    
  # Свободная память (RAM)
  - platform: template
    name: "Free Heap"
    lambda: |-
      return heap_caps_get_free_size(MALLOC_CAP_INTERNAL) / 1024.0;
    unit_of_measurement: 'kB'
    update_interval: 10s
    accuracy_decimals: 1
    
  # Процент свободной памяти
  - platform: template
    name: "Free Heap %"
    lambda: |-
      float total = heap_caps_get_total_size(MALLOC_CAP_INTERNAL);
      float free = heap_caps_get_free_size(MALLOC_CAP_INTERNAL);
      return (free / total) * 100.0;
    unit_of_measurement: '%'
    update_interval: 10s
    accuracy_decimals: 1
    
  # Время выполнения главного цикла
  - platform: debug
    loop_time:
      name: "Loop Time"

text_sensor:
  # Версия ESPHome
  - platform: version
    name: "ESPHome Version"
    hide_timestamp: true
  
  # Номер билда
  - platform: template
    name: "Build Number"
    lambda: |-
      return {"${build_number}"};
    update_interval: never
    
  # IP адрес
  - platform: wifi_info
    ip_address:
      name: "IP Address"

# Hydroponic Controller (external component from GitHub)
external_components:
  - source: github://chymaslik/hydroponic-tower@main
    components: [ hydroponic_controller ]

hydroponic_controller:
  pump_id: water_pump
  light_id: lighting
  time_id: sntp_time
  web_server_id: web_srv
  on_minutes: 5
  off_minutes: 15
  enabled: false

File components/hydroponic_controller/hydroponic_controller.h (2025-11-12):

#pragma once

#include "esphome/core/component.h"
#include "esphome/core/preferences.h"
#include "esphome/components/fan/fan.h"
#include "esphome/components/light/light_state.h"
#include "esphome/components/time/real_time_clock.h"
#include "esphome/components/web_server/web_server.h"
#include "esphome/components/web_server_base/web_server_base.h"
#include "esphome/components/web_server_idf/web_server_idf.h"

namespace esphome {
namespace hydroponic_controller {

static const char *const TAG = "hydroponic_controller";

// Структура для хранения настроек в энергонезависимой памяти
struct Settings {
  bool enabled = false;
  int on_minutes = 5;
  int off_minutes = 15;
  bool light_sched_enabled = false;
  int light_on_minutes = 1080;   // 18:00
  int light_off_minutes = 540;   // 09:00
  uint32_t crc = 0;
  
  uint32_t calculate_crc() const {
    uint32_t hash = 2166136261u;
    const uint8_t *data = reinterpret_cast<const uint8_t*>(this);
    for (size_t i = 0; i < sizeof(Settings) - sizeof(crc); i++) {
      hash ^= data[i];
      hash *= 16777619u;
    }
    return hash;
  }
};

class HydroponicController : public Component {
 public:
  void set_pump(fan::Fan *pump) { pump_ = pump; }
  void set_light(light::LightState *light) { light_ = light; }
  void set_clock(time::RealTimeClock *clock) { clock_ = clock; }
  void set_server(web_server::WebServer *server) { server_ = server; }
  void set_durations(int on_min, int off_min) { 
    on_minutes_ = on_min; 
    off_minutes_ = off_min; 
  }
  void set_enabled(bool e) { enabled_ = e; }

  void setup() override {
    ESP_LOGI(TAG, "========================================");
    ESP_LOGI(TAG, ">>> Setting up Hydroponic Controller...");
    
    // Загрузка сохранённых настроек из энергонезависимой памяти
    pref_ = global_preferences->make_preference<Settings>(fnv1_hash("hydro_settings"));
    Settings loaded;
    ESP_LOGI(TAG, "Attempting to load settings from NVS...");
    if (pref_.load(&loaded)) {
      ESP_LOGI(TAG, "Settings found in NVS, checking CRC...");
      if (loaded.crc == loaded.calculate_crc()) {
        enabled_ = loaded.enabled;
        on_minutes_ = loaded.on_minutes;
        off_minutes_ = loaded.off_minutes;
        light_sched_enabled_ = loaded.light_sched_enabled;
        light_on_minutes_ = loaded.light_on_minutes;
        light_off_minutes_ = loaded.light_off_minutes;
        ESP_LOGI(TAG, "✓ Settings loaded from flash successfully!");
        ESP_LOGI(TAG, "  Pump schedule: %s, ON=%dmin, OFF=%dmin", 
                 enabled_ ? "enabled" : "disabled", on_minutes_, off_minutes_);
        ESP_LOGI(TAG, "  Light schedule: %s, ON=%02d:%02d, OFF=%02d:%02d",
                 light_sched_enabled_ ? "enabled" : "disabled",
                 light_on_minutes_/60, light_on_minutes_%60,
                 light_off_minutes_/60, light_off_minutes_%60);
      } else {
        ESP_LOGW(TAG, "✗ Settings CRC mismatch, using defaults");
      }
    } else {
      ESP_LOGI(TAG, "No saved settings found, using defaults");
    }
    
    last_change_ms_ = millis();
    running_on_ = false;
    register_routes_();
    if (enabled_) start_cycle_();
    ESP_LOGI(TAG, ">>> Hydroponic Controller setup complete!");
    ESP_LOGI(TAG, "========================================");
  }

  void loop() override {
    // Pump cycle logic
    if (enabled_) {
      const uint32_t now = millis();
      const uint32_t period_ms = (running_on_ ? on_minutes_ : off_minutes_) * 60000UL;
      if (now - last_change_ms_ >= period_ms) {
        running_on_ = !running_on_;
        last_change_ms_ = now;
        if (running_on_) {
          if (pump_ != nullptr) {
            pump_->turn_on().perform();
            ESP_LOGI(TAG, "Pump ON (scheduled cycle)");
          }
        } else {
          if (pump_ != nullptr) {
            pump_->turn_off().perform();
            ESP_LOGI(TAG, "Pump OFF (scheduled cycle)");
          }
        }
      }
    }

    // Light schedule logic
    if (light_sched_enabled_ && clock_ != nullptr) {
      auto time = clock_->now();
      if (time.is_valid()) {
        int current_minutes = time.hour * 60 + time.minute;
        bool should_be_on = false;
        
        if (light_on_minutes_ < light_off_minutes_) {
          should_be_on = (current_minutes >= light_on_minutes_ && current_minutes < light_off_minutes_);
        } else {
          should_be_on = (current_minutes >= light_on_minutes_ || current_minutes < light_off_minutes_);
        }
        
        if (light_ != nullptr) {
          bool is_on = light_->current_values.is_on();
          if (should_be_on && !is_on) {
            light_->turn_on().perform();
            ESP_LOGI(TAG, "Lighting ON (scheduled)");
          } else if (!should_be_on && is_on) {
            light_->turn_off().perform();
            ESP_LOGI(TAG, "Lighting OFF (scheduled)");
          }
        }
      }
    }
  }

  void dump_config() override {
    ESP_LOGCONFIG(TAG, "Hydroponic Controller:");
    ESP_LOGCONFIG(TAG, "  NVS Status: %s", settings_loaded_from_nvs_ ? "✓ Loaded from flash" : "✗ Using defaults");
    ESP_LOGCONFIG(TAG, "  Pump ON: %d min", on_minutes_);
    ESP_LOGCONFIG(TAG, "  Pump OFF: %d min", off_minutes_);
    ESP_LOGCONFIG(TAG, "  Pump Schedule: %s", enabled_ ? "enabled" : "disabled");
    ESP_LOGCONFIG(TAG, "  Light ON: %02d:%02d", light_on_minutes_/60, light_on_minutes_%60);
    ESP_LOGCONFIG(TAG, "  Light OFF: %02d:%02d", light_off_minutes_/60, light_off_minutes_%60);
    ESP_LOGCONFIG(TAG, "  Light Schedule: %s", light_sched_enabled_ ? "enabled" : "disabled");
  }

 protected:
  void start_cycle_() {
    last_change_ms_ = millis();
    running_on_ = true;
    if (pump_ != nullptr) {
      pump_->turn_on().perform();
      ESP_LOGI(TAG, "Pump cycle started");
    }
  }

  void stop_cycle_() {
    if (pump_ != nullptr) {
      pump_->turn_off().perform();
    }
    running_on_ = false;
    ESP_LOGI(TAG, "Pump cycle stopped");
  }
  
  void save_settings_() {
    ESP_LOGI(TAG, ">>> save_settings_() called <<<");
    Settings s;
    s.enabled = enabled_;
    s.on_minutes = on_minutes_;
    s.off_minutes = off_minutes_;
    s.light_sched_enabled = light_sched_enabled_;
    s.light_on_minutes = light_on_minutes_;
    s.light_off_minutes = light_off_minutes_;
    s.crc = s.calculate_crc();
    
    ESP_LOGI(TAG, "Saving: enabled=%d, on=%d, off=%d, light_sched=%d", 
             s.enabled, s.on_minutes, s.off_minutes, s.light_sched_enabled);
    
    if (pref_.save(&s)) {
      ESP_LOGI(TAG, "✓ Settings saved to flash successfully!");
    } else {
      ESP_LOGE(TAG, "✗ FAILED to save settings to flash!");
    }
  }

  void register_routes_();
  std::string build_index_() const;

  fan::Fan *pump_{nullptr};
  light::LightState *light_{nullptr};
  time::RealTimeClock *clock_{nullptr};
  web_server::WebServer *server_{nullptr};
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

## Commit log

2025-11-09 Initial commit: Hydroponic Tower ESPHome component
    [1-way_planting_module_hollow_without_m3.stl, 10mmTo8mmHoseBarbAdapter.stl, 3-way_planting_module_hollow.stl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]
2025-11-12 Enhance hydroponics.yaml with performance monitoring sensors and remove Bluetooth configuration
2025-11-12 Update hydroponics.yaml with build number and OTA support, and add a template sensor for build tracking
